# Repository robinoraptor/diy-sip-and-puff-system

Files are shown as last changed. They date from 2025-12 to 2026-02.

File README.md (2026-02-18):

# Sip & Puff Mouse Controller

> Ein adaptives Eingabesystem für Menschen mit eingeschränkter Fingermotorik

Prototyp v3.0 b

---

## 📖 Über das Projekt

Dieses Projekt entstand im Rahmen eines **Human Factors (HF) Projekts** in Kooperation mit der **Hochschule Furtwangen** und **Musiklusion** (https://www.musiklusion.de/mundmaus/) und verfolgt die Fragestellung:

> **"Wie können durch eine Assistenzlösung zusätzliche, intuitiv nutzbare Freiheitsgrade geschaffen werden, die Menschen mit eingeschränkter Fingermotorik das selbstständige Ausführen der Maussteuerung ermöglichen?"**

### Definition Freiheitsgrad

*"Ein Freiheitsgrad ist eine (kontinuierliche) Dimension, die vom Eingabegerät erfasst und vom Benutzer unabhängig gesteuert werden kann."*  
— Seinfeld et al. (2020): User Representations in Human-Computer Interaction

---

## 🎯 Projektziele

Das System wurde entwickelt mit Fokus auf:

1. **Ausdrucksstarke Schnittstelle**  
   Maximaler digitaler Output bei minimalem physischem Aufwand

2. **Nutzerzentrierung**  
   Übertragbarkeit auf alle Menschen mit ähnlichen Einschränkungen

3. **Alltagsverbesserung**  
   Mehr Selbstständigkeit bei der PC-Bedienung für Menschen mit Einschränkungen

4. **Intuitive Bedienung**  
   Natürliche Interaktion durch Sip & Puff (Saug- und Blastechnik)

### Inspiration

Das Projekt orientiert sich an professionellen Assistenzsystemen wie dem **Quadstick** und ähnlichen kommerziellen Produkten, bietet aber eine **Open-Source-Alternative** zum Selbstbau.

---

## 🔄 Entwicklungsprozess & Prototypen

Die Entwicklung erfolgte iterativ in mehreren Prototyp-Versionen:

### Version 1.0 - Proof of Concept
Prototyp v1.0 a
Prototyp v1.0 b

**Features:**
- Basis-Funktionalität (Sip & Puff für Klicks)
- Joystick für 2D-Mausbewegung
- Lötverbindung der Komponenten
- Einfacher Arduino-Code

**Erkenntnisse:**
- Drucksensor-Kalibrierung essentiell
- Schwellwerte müssen anpassbar sein
- Deadzone notwendig für präzise Steuerung
- Geschwindigkeitsanpassung wichtig

### Version 2.0 - GUI-gesteuert
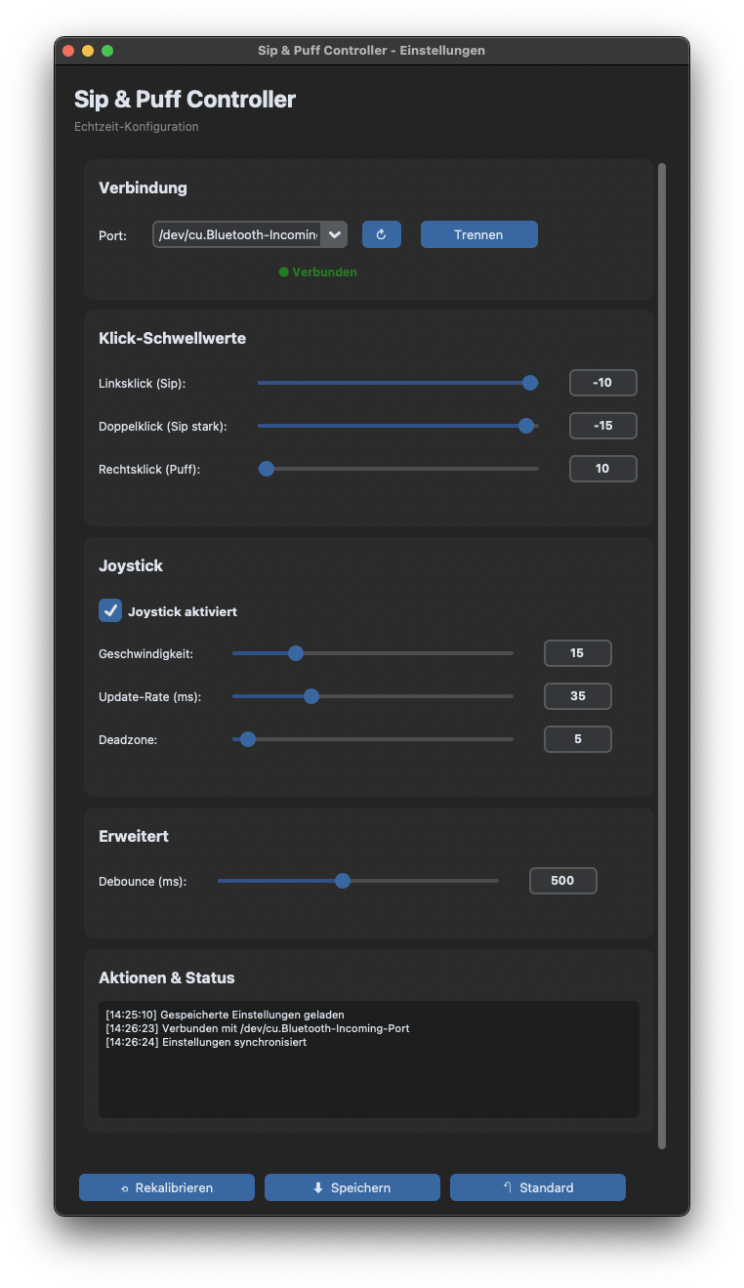
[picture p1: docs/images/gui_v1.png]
GUI v1.0

Prototyp v2.0 a
Prototyp v2.0 b

**Features:**
- Erste vollständige GUI-Integration
- Echtzeit-Parameteranpassung
- Persistente Einstellungen
- Moderne CustomTkinter-UI
- Breiteres Mundstück
- Erweiterung des Mundstücks um Luer-Lock-Adapter um optinalen PTFE-Atemfilter hinzuzufügen

**Erkenntnisse:**
- Live-Anpassung drastisch verbessert Nutzbarkeit
- Individuelle Profile essentiell
- Begrenzung der Bakterienbildung essentiell

### Version 3.0 - Polished Prototype
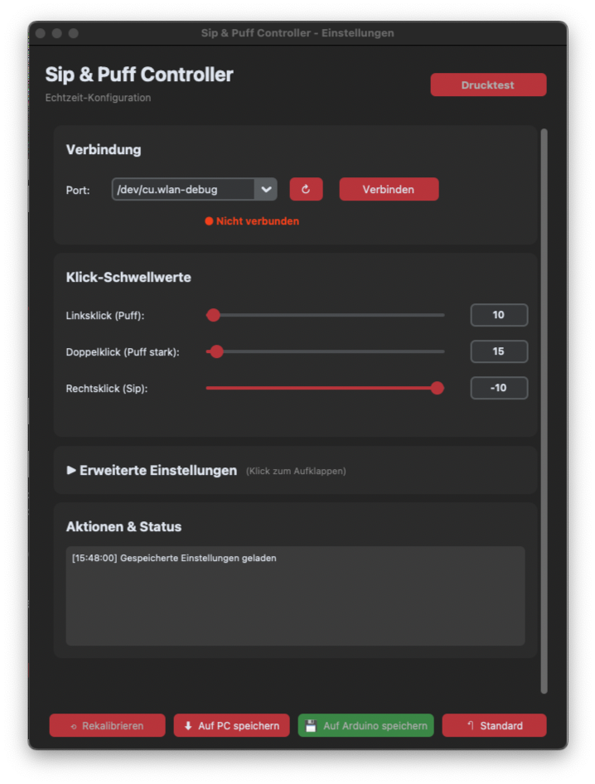
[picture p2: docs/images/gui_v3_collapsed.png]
GUI v2.0

Prototyp v3.0 a
Prototyp v3.0 b

**Features:**
- Überarbeitete GUI für übersichtlichere Bedienung
- Exportieren der GUI als eigenständige Desktop-Anwendung möglich
- Speichern der Einstellungen auf dem Gerät selbst (Plug & Play)
- Überarbeitung der Scroll-Funktionalität durch Mappen auf Joyatick-Bewegungen
- Schlichtes und modernes Gehäuse für die Technik
- Einfaches Austuschen der Gelenkarmverbindung

**Erkenntnisse:**
- Speichern auf Gerät erhöht Plug & Play Charakter drastisch
- Überdecken von verbauten LEDs verhindern mögliche Ablenkungen
- Austauschbarkeit der Armverbingung trägt zur erhöhter Unabhängigkeit bei

---

## ✨ Features

### Hardware
- ✅ **MPXV7002DP Drucksensor** für bidirektionale Druckmessung (Saugen/Blasen)
- ✅ **Analoger Joystick** für präzise 2D-Mausbewegung oder Scrollen
- ✅ **Arduino Pro Micro** als USB-HID-Gerät (native Mausfunktion)
- ✅ **Modularer Aufbau** für einfache Anpassungen

### Software
- ✅ **Moderne GUI** mit CustomTkinter für Echtzeit-Konfiguration
- ✅ **Live-Parameteranpassung** ohne Arduino-Neustart
- ✅ **Persistente Einstellungen** (JSON & Arduino EEPROM)
- ✅ **Drei Klick-Modi**: Linksklick, Doppelklick, Rechtsklick
- ✅ **Scroll-Funktionalität** für vertikales Scrollen
- ✅ **Adaptive Schwellwerte** (-400 bis +400)
- ✅ **Joystick aktivierbar/deaktivierbar**
- ✅ **Standalone Desktop-Anwendung** (.app/.exe) ohne Python-Installation

GUI Screenshot

---

## 🛠️ Hardware-Komponenten

| Komponente | Typ | Funktion | Ungefähre Kosten | Link |
|---|-----|---|---|---|
| Arduino Pro Micro | ATmega32U4 | Mikrocontroller mit nativer USB-HID-Unterstützung | ~8 € | https://www.amazon.de/EntwicklungBoards-Binghe-Mikrocontroller-Entwicklungsboard-Selbst-USB-Updater/dp/B0D69JLJ97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 |
| MPXV7002DP | Drucksensor | Bidirektionaler Differenzdrucksensor (±2 kPa) | ~24 € | https://www.amazon.de/dp/B08D6JDJ4D?ref=ppx_yo2ov_dt_b_fed_asin_title |
| Analoger Joystick | 2-Achsen | XY-Achsen für Mausbewegung | ~1 € | https://www.roboter-bausatz.de/p/joystick-modul-2-achsen |
| Schlauch 2.5mm ID x 4mm OD x 1m | Silikon (Lebensmittelecht) | Für Sip & Puff Eingabe | ~4 € | https://www.amazon.de/dp/B0BZXR88VD?ref=ppx_yo2ov_dt_b_fed_asin_title&th=1 |
| Schlauch 3mm ID x 6mm OD x 1.5m | Silikon (Lebensmittelecht) | Für Sip & Puff Eingabe | ~5 € | https://www.amazon.de/dp/B0CXPW74GZ?ref=ppx_yo2ov_dt_b_fed_asin_title&th=1 |
| PTFE Filter | Hydrophob | Hygiene & Schutz gegen Flüssigkeit | ~14 € | https://www.amazon.de/dp/B07KWW7ZXF?ref=ppx_yo2ov_dt_b_fed_asin_title&th=1 |
| Luer Lock Adapter | Weiblich | Verbindung von Filter & Schlauch | ~7 € | https://www.amazon.de/dp/B0BMFJSJP1?ref=ppx_yo2ov_dt_b_fed_asin_title |
| Luer Lock Adapter | Männlich | Verbindung von Filter & Schlauch | ~8 € | https://www.amazon.de/dp/B0B8CJVX3S?ref=ppx_yo2ov_dt_b_fed_asin_title |
| Diverse | Kabel, LEDs, Gehäuse | Verkabelung und Montage | ~5-10 € |
| **Gesamt** | | | **~75-80 €** |

---

## 🔌 Schaltplan

### Pin-Belegung Arduino Pro Micro

```
MPXV7002DP Drucksensor:
├─ VCC  → 5V (Arduino)
├─ GND  → GND (Arduino)
└─ OUT  → A0 (Analog)

Joystick:
├─ VCC  → RAW (5V Arduino)
├─ GND  → GND (Arduino, optional über Kippschalter)
├─ VRx  → A2 (Analog)
└─ VRy  → A1 (Analog)

Optionaler Reset-Button (Für Debugging):
├─ Pin 1 → GND
└─ Pin 2 → RST
```

---

## 📦 Installation

### Voraussetzungen

**Hardware:**
- Arduino Pro Micro (oder kompatibel)
- USB-Kabel (Micro-USB)
- Aufgebaute Schaltung (siehe Schaltplan)

**Software:**
- [PlatformIO](https://platformio.org/) oder Arduino IDE
- Python 3.7+ (für GUI-Entwicklung, nicht für fertige Desktop-App)
- Git (optional)

### 1. Repository klonen

```bash
git clone https://github.com/robinoraptor/sip-puff-controller.git
cd sip-puff-controller
```

### 2. Arduino-Code flashen

#### Mit PlatformIO (empfohlen):

```bash
cd arduino/
pio run --target upload
```

#### Mit Arduino IDE:
1. `arduino/src/main.cpp` öffnen
2. Board auswählen: **Tools → Board → SparkFun Pro Micro (5V, 16 MHz)**
3. Port auswählen: **Tools → Port → [Dein Port]**
4. Hochladen: **Sketch → Upload**

### 3. GUI verwenden

#### Python-Version (für Entwickler)

**Automatisch:**

**Linux/macOS:**
```bash
cd gui/
./start_gui.sh
```

**Windows:**
```bash
cd gui/
start_gui.bat
```

**Manuell:**

```bash
cd gui/
pip install -r requirements.txt
python sippuff_gui.py
```

---

## 🖥️ Desktop-Anwendung erstellen

Du möchtest die GUI als **standalone .app/.exe** verteilen, ohne dass Python installiert sein muss?

### Voraussetzungen

```bash
cd gui/
pip install -r requirements.txt
```

Das installiert automatisch auch PyInstaller.

### Build-Prozess

#### macOS (.app):

```bash
cd gui/

# Build-Script ausführbar machen (nur einmal nötig)
chmod +x build_mac_linux.sh

# Desktop-App erstellen
./build_mac_linux.sh
```

**Ergebnis:** `dist/SipPuffController.app` (~90-130 MB)

#### Windows (.exe):

```cmd
cd gui

:: Desktop-App erstellen
build_windows.bat
```

**Ergebnis:** `dist\SipPuffController.exe` (~80-120 MB)

#### Linux (Binary):

```bash
cd gui/

# Build-Script ausführbar machen (nur einmal nötig)
chmod +x build_mac_linux.sh

# Desktop-App erstellen
./build_mac_linux.sh
```

**Ergebnis:** `dist/SipPuffController` (~90-130 MB)

### Die fertige Anwendung

Nach dem Build findest du die Anwendung in `gui/dist/`:

```
gui/
├── dist/
│   └── SipPuffController.app    (Mac)
│       SipPuffController.exe    (Windows)
│       SipPuffController        (Linux)
└── build/                        (temporäre Dateien)
```

**Die Anwendung enthält:**
- ✅ Python Runtime
- ✅ Alle Bibliotheken (CustomTkinter, PySerial, etc.)
- ✅ GUI-Code
- ✅ Theme-Dateien
- ✅ Komplettes System in einer Datei!

### Verteilen

**Einfach die .app/.exe kopieren und weitergeben!**

Keine Installation nötig, einfach:
1. Kopieren auf anderen Computer
2. Doppelklick
3. Arduino anschließen
4. Fertig! 🚀

### Wichtige Hinweise

**macOS:**
- Beim ersten Start: Rechtsklick → "Öffnen" (wegen Gatekeeper)
- Oder: Systemeinstellungen → Sicherheit → "Trotzdem öffnen"

**Windows:**
- Antivirus könnte Warnung zeigen (False Positive)
- "Weitere Informationen" → "Trotzdem ausführen"

**Linux:**
- Ausführbar machen: `chmod +x SipPuffController`
- Dann starten: `./SipPuffController`

### Build bereinigen

```bash
# Alte Builds löschen
cd gui/
rm -rf dist/ build/ *.spec

# Neu builden
./build_mac_linux.sh  # oder build_windows.bat
```

---

## 🚀 Verwendung

### Ersteinrichtung

1. **Arduino anschließen**
   - System kalibriert automatisch beim Start
   - ⚠️ **Wichtig:** NICHT in den Schlauch pusten/saugen während der Kalibrierung!

2. **GUI starten**
   - Desktop-App: Doppelklick auf `.app`/`.exe`
   - Oder: `python sippuff_gui.py`

3. **Verbinden**
   - Port auswählen (z.B. COM3 oder /dev/ttyACM0)
   - "Verbinden" klicken
   - GUI lädt automatisch die Arduino-Einstellungen

4. **Einstellungen anpassen**
   - Mit Slidern experimentieren
   - Echtzeit-Feedback im Log
   - Drucktest nutzen für optimale Schwellwerte

#### Standard-Belegung:

| Aktion | Eingabe | Beschreibung |
|---|---|---|
| **Linksklick** | Puff (Blasen) > 10 | Leichtes Blasen |
| **Doppelklick** | Puff (Blasen) > 15 | Kräftiges Blasen |
| **Rechtsklick** | Sip (Saugen) < -10 | Leichtes Ansaugen |
| **Scroll Up** | Joystick | horizontale Bewegung nach Links |
| **Scroll Down** | Joystick | horizontale Bewegung nach Rechts |
| **Mausbewegung** | Joystick | 2D-Bewegung in alle Richtungen |

#### Anpassbare Parameter:

**Klick-Schwellwerte:**
- Linksklick (Puff): 0 bis 400
- Doppelklick (Puff): 0 bis 400
- Rechtsklick (Sip): -400 bis 0

**Joystick:**
- Geschwindigkeit: 5-50
- Update-Rate: 10-100ms
- Deadzone: 0-100

**Weitere:**
- Debounce: 100-1000ms
- Joystick an/aus
- Scroll an/aus

### Einstellungen speichern

**Auf PC speichern:**
- Klicke "⬇ Auf PC speichern"
- Wird in `~/.sippuff/sippuff_config.json` gespeichert
- Funktioniert auch in Desktop-App!

**Auf Arduino speichern:**
- Klicke "💾 Auf Arduino speichern"
- Wird im Arduino EEPROM gespeichert
- Arduino funktioniert jetzt **Plug & Play** - auch ohne PC!
- Einstellungen bleiben dauerhaft erhalten

**Standard wiederherstellen:**
- Klicke "↶ Standard"
- Lädt Standardwerte aus `sippuff_defaults.json`

### Workflow: Arduino als Master

Das System ist so konzipiert, dass **der Arduino die Einstellungen speichert**:

```
1. Arduino anschließen
2. GUI öffnen → Verbinden
3. GUI lädt automatisch Arduino-Einstellungen ✅
4. In GUI anpassen (optional)
5. "💾 Auf Arduino speichern" (optional)
6. Beim nächsten Start: Arduino hat alles gespeichert!
```

**Vorteil:** Arduino funktioniert überall gleich - egal an welchem PC!

---

## 🔧 Konfiguration

### Schwellwerte anpassen

Die Empfindlichkeit kann individuell angepasst werden:

```
Für Nutzer mit schwächerer Atemkontrolle:
├─ Linksklick (Puff): 5
├─ Doppelklick (Puff): 8
├─ Rechtsklick (Sip): -5
├─ Scroll Down (Puff): 3
└─ Scroll Up (Sip): -3

Für Nutzer mit stärkerer Atemkontrolle:
├─ Linksklick (Puff): 30
├─ Doppelklick (Puff): 50
├─ Rechtsklick (Sip): -30
├─ Scroll Down (Puff): 10
└─ Scroll Up (Sip): -10
```

**Tipp:** Nutze den **Drucktest** in der GUI, um deine optimalen Werte zu finden!

### Standard-Werte ändern

Editiere `~/.sippuff/sippuff_defaults.json`:

```json
{
  "click_left": 10,
  "click_double": 15,
  "click_right": -10,
  "scroll_up": -5,
  "scroll_down": 5,
  "scroll_speed": 1,
  "scroll_enabled": true,
  "wavelength": 15,
  "period": 35,
  "deadzone": 25,
  "debounce": 500,
  "joystick_enabled": true
}
```

---

## 🔬 Technische Details

### Arduino-Firmware

- **Sprache:** C++ (Arduino Framework)
- **Bibliotheken:** `Mouse.h` (native USB-HID), `EEPROM.h`
- **Sampling-Rate:** 100 Hz (10ms Loop)
- **Kalibrierung:** Automatisch beim Start (50 Samples, 1 Sekunde)
- **Serial-Protokoll:** 115200 Baud für GUI-Kommunikation
- **Persistenz:** EEPROM-Speicher für Plug & Play Betrieb

### GUI-Anwendung

- **Framework:** CustomTkinter (moderne UI)
- **Kommunikation:** PySerial
- **Architektur:** Event-driven mit Threading
- **Build-System:** PyInstaller für standalone Apps
- **Config-Speicher:** `~/.sippuff/` (User-Home-Directory)
- **Plattformen:** Windows, macOS, Linux

### Desktop-App Details

**PyInstaller-Build:**
- `--onefile`: Einzelne ausführbare Datei
- `--windowed`: Keine Konsole (nur GUI)
- `--add-data`: Theme-Dateien eingebettet
- Alle Abhängigkeiten inkludiert
- Keine Python-Installation erforderlich

**Dateigröße:**
- Mac: ~90-130 MB (.app Bundle)
- Windows: ~80-120 MB (.exe)
- Linux: ~90-130 MB (Binary)

---

## 📚 Wissenschaftlicher Hintergrund

### Literatur

**Seinfeld, S., Feuchtner, T., Maselli, A. & Müller, J. (2020).**  
*User Representations in Human-Computer Interaction.*  
Human-Computer Interaction, 36(5–6), 400–438.  
https://doi.org/10.1080/07370024.2020.1724790

### Verwandte Projekte

- **Quadstick** - Kommerzielles Sip & Puff System
- **Xbox Adaptive Controller** - Microsoft's Adaptive Gaming Controller

---

## ⚠️ Sicherheitshinweise

### Wichtig für die Nutzung:

1. **Hygiene**
   - Mundstück täglich reinigen/desinfizieren
   - Schlauch regelmäßig austauschen
   - Bei mehreren Nutzern: individuelle Mundstücke verwenden

2. **Gesundheit**
   - Bei Schwindel/Unwohlsein sofort pausieren
   - Nicht zu stark/häufig pusten (Hyperventilation vermeiden)
   - Regelmäßige Pausen einlegen

3. **Technisch**
   - System nicht unbeaufsichtigt mit anderen Nutzern betreiben
   - Bei Fehlfunktion sofort vom Computer trennen
   - Keine Modifikationen an medizinischen Komponenten

4. **Medizinisch**
   - Dieses System ist **kein medizinisches Produkt**
   - Keine CE-Kennzeichnung für Medizinprodukte
   - Bei medizinischer Nutzung: Rücksprache mit Fachpersonal

---

## 🎓 Hochschule Furtwangen

Entwickelt im Rahmen eines Human Factors Projekts an der **Hochschule Furtwangen University (HFU)**.

**Fakultät:** Engineering Technology  
**Studiengang:** Human Factors  
**Semester:** 2. Semester

---

## 📄 Lizenz

Dieses Projekt steht unter der MIT-Lizenz - siehe [LICENSE](LICENSE) für Details.

---

## 🤝 Beitragen

Contributions sind willkommen! Bitte öffne ein Issue oder Pull Request auf GitHub.

---

## 📧 Kontakt

Bei Fragen oder Anregungen:
- GitHub Issues: [github.com/robinoraptor/sip-puff-controller/issues](https://github.com/robinoraptor/sip-puff-controller/issues)

---

**Entwickelt mit ❤️ für Assistive Technology**

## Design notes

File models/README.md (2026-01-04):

# Bauteile

---

In diesen Ordnern sind alle Dateien zu den physischen Bauteilen zu finden, die mittels 3D-Druck-Verfahren hergestellt werden müssen. In manche Teile sind Einschmelzgewinde einzulassen. Diese werden mit einem Lötkolben oder Ähnlichem erhitzt und in das fertige Bauteil gedrückt. Somit sorgen diese für eine stärkere und nachhaltigere Verbindung. Sollten keine Einschmelzgewinde vorhanden sein, können die STEP-Dateien so bearbeitet werden, dass eine Schraube alleine für die Fixierung ausreichend ist. Für den Mainframe, an den die elektronischen Bauteile befestigt werden, werden 11 M2 Gewinde mit den Maßen 3x3.5mm verwendet. Zur Befestigung werden 6 M2x4mm Schrauben verwendet. Das Frontcover wird am Mainframe mit Hilfe von 2 M2x6mm Schrauben befestigt. Das Backcover wiederum benötigt 3 M2x4mm Schrauben. Dort werden zudem 4 3x3.5mm Einschmelzgewinde eingesetzt, um einen Adapter zu einem Gelenkarm zu befestigen. Mit dem Bereitgestellten BallJointAdapter benötigt man 4 M2x6mm und diesen an dem Gerät zu befestigen.

---

## STEP-Dateien

Die STEP-Dateien können in CAD-Programmen wie Shapr3D weiter angepasst werden. Hier können zum Beispiel Maße auf andere Bauteile oder Befestigungsmöglichkeiten angepasst werden.

## 3MF-Dateien

Die 3MF-Dateien können direkt in das 3D-Druck Slicer Programm BambuStudio gezogen werden. Dieser Slicer wird empfohlen, wenn die 3D-Drucker von BambuLab verwendet werden. Diese Dateien beinhalten alle Druck-Einstellungen, die für den ersten Bau verwendet wurden.

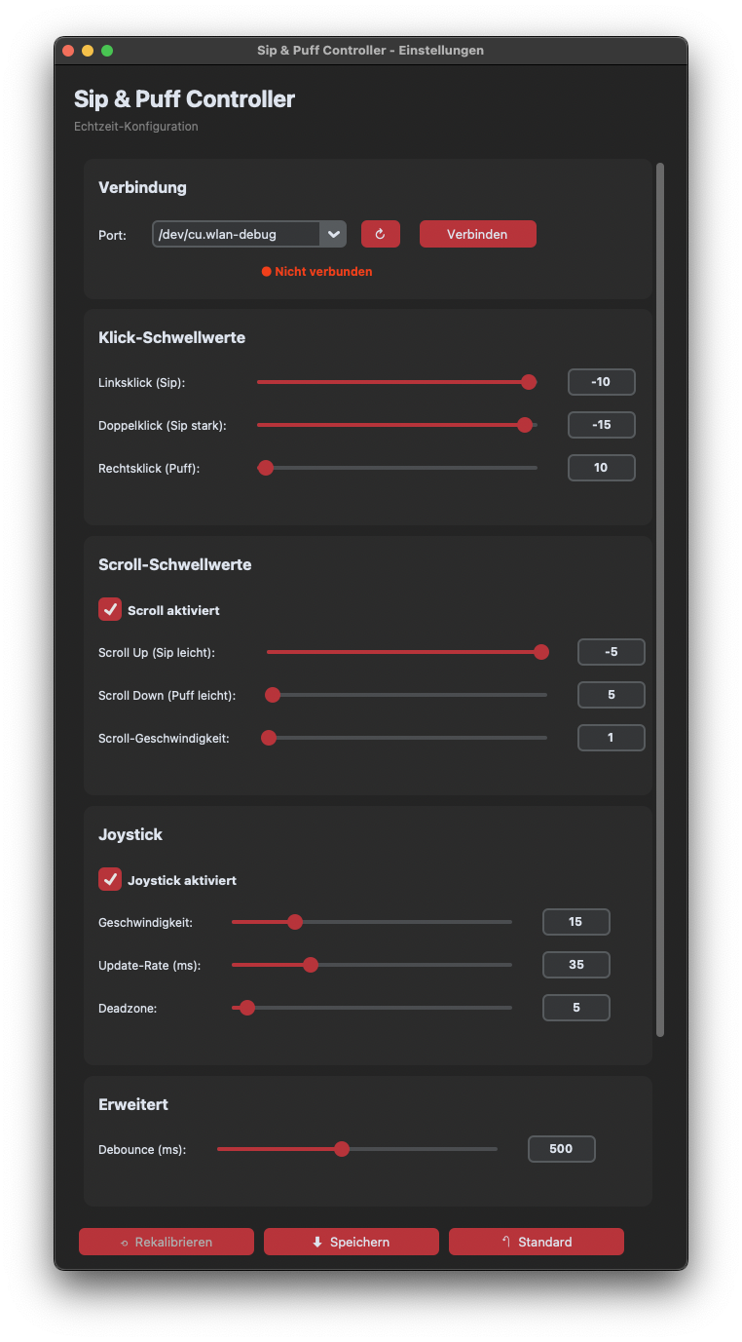
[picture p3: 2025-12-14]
docs/images/gui_v2.png

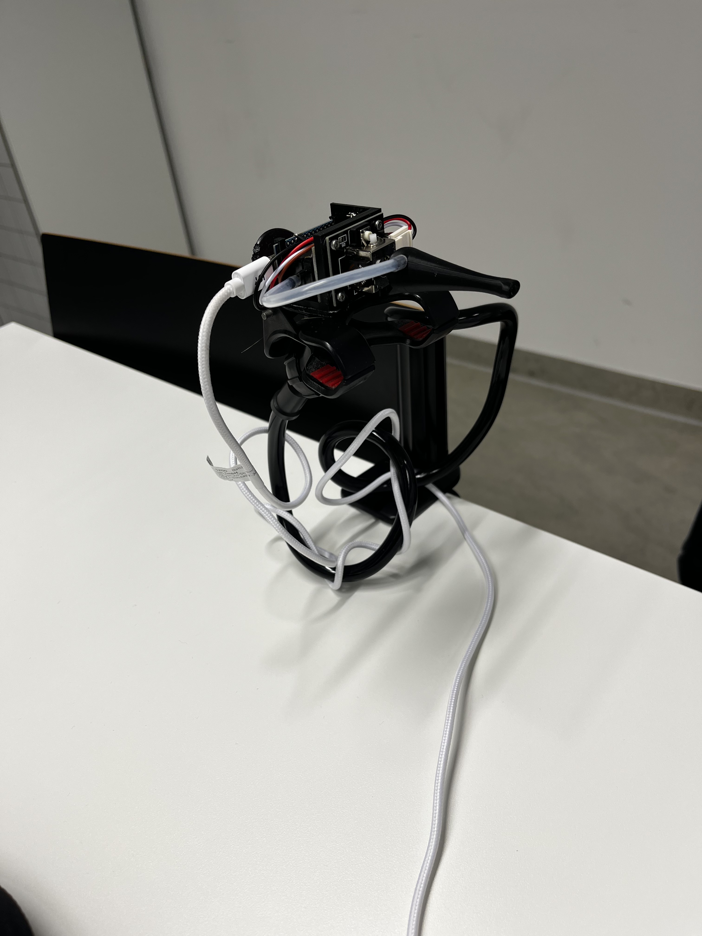
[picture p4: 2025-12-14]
docs/images/prototype_v1_b.jpg

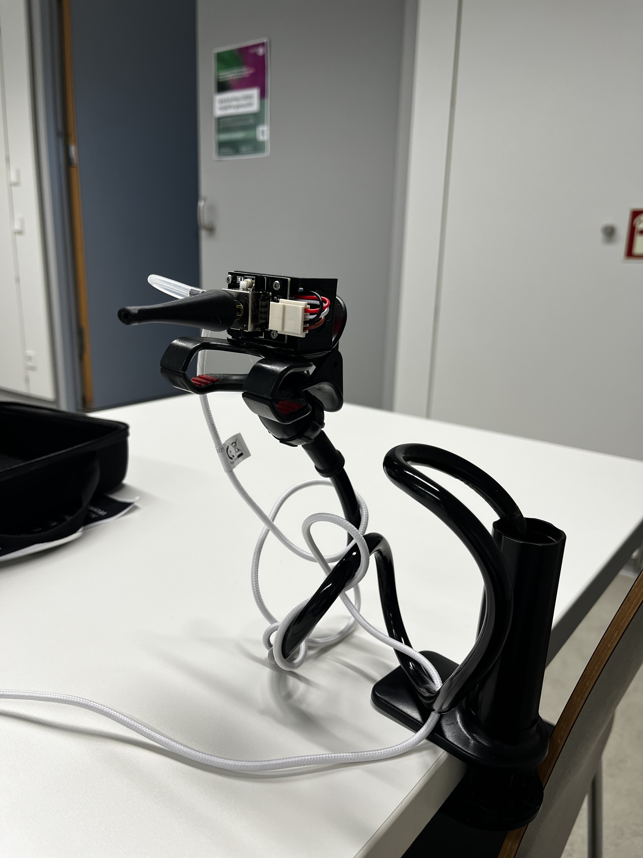
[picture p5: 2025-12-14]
docs/images/prototype_v1_a.jpg

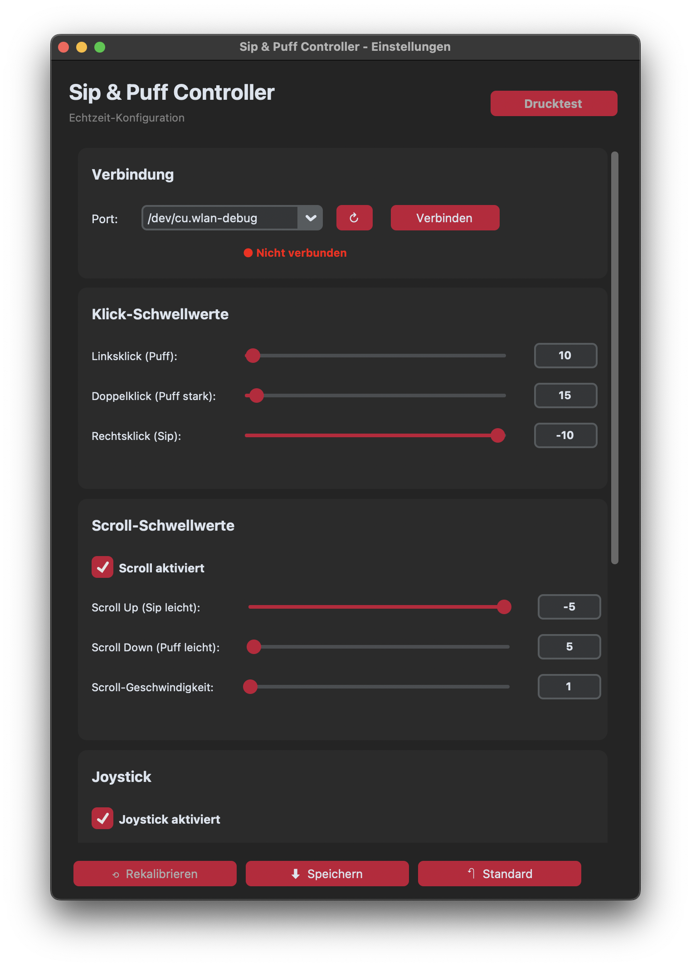
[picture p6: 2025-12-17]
docs/images/gui_v3.png

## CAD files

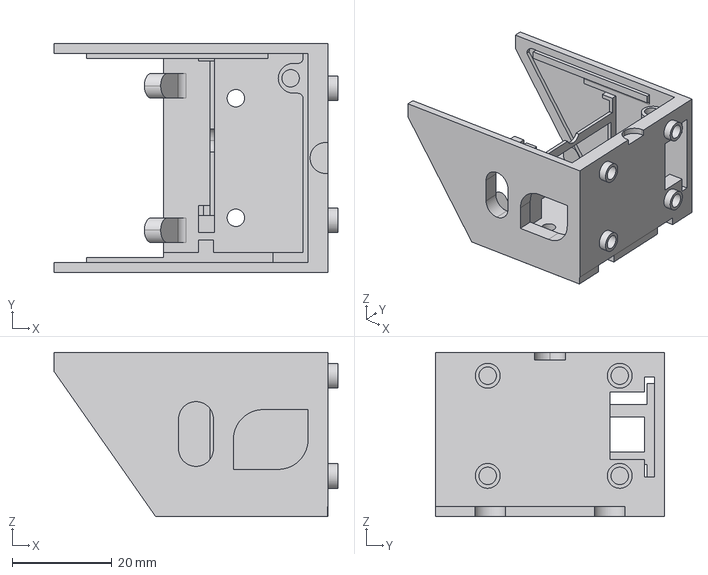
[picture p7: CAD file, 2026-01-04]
models/Step/Mainframe.step
57.0 x 46.0 x 33.0 mm

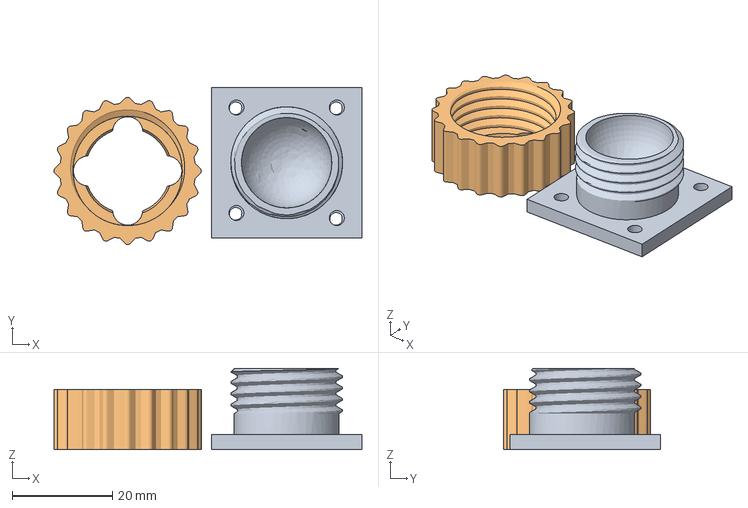
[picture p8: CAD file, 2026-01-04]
models/3mf/BallJointAdapter.3mf
61.3 x 31.3 x 16.2 mm
Ball Socket Lock1.stl_3
nut.stl

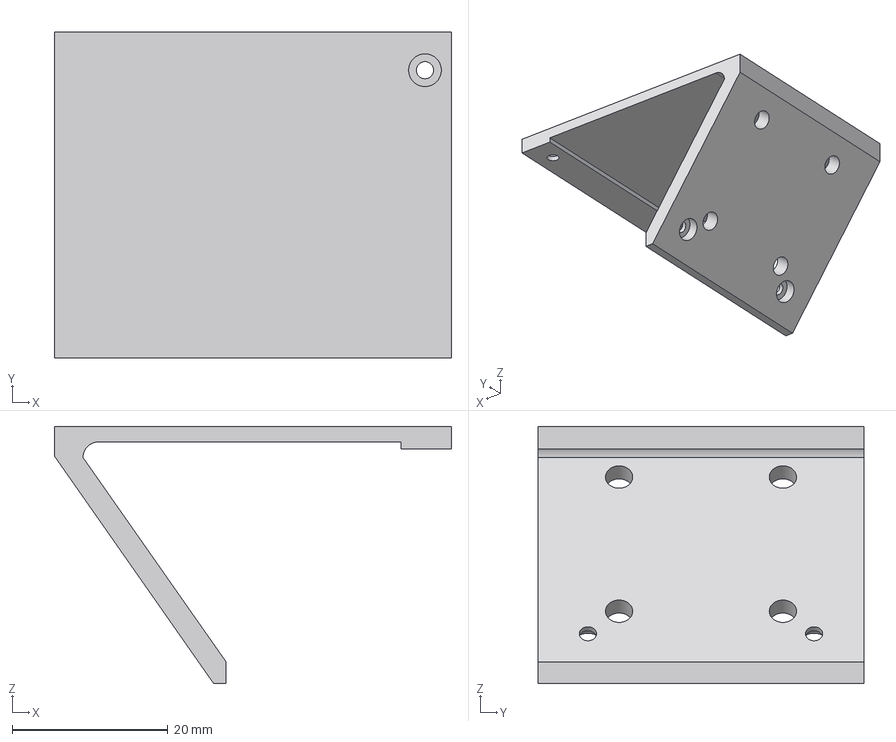
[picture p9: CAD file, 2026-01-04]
models/Step/Backcover.step
50.9 x 41.8 x 33.0 mm

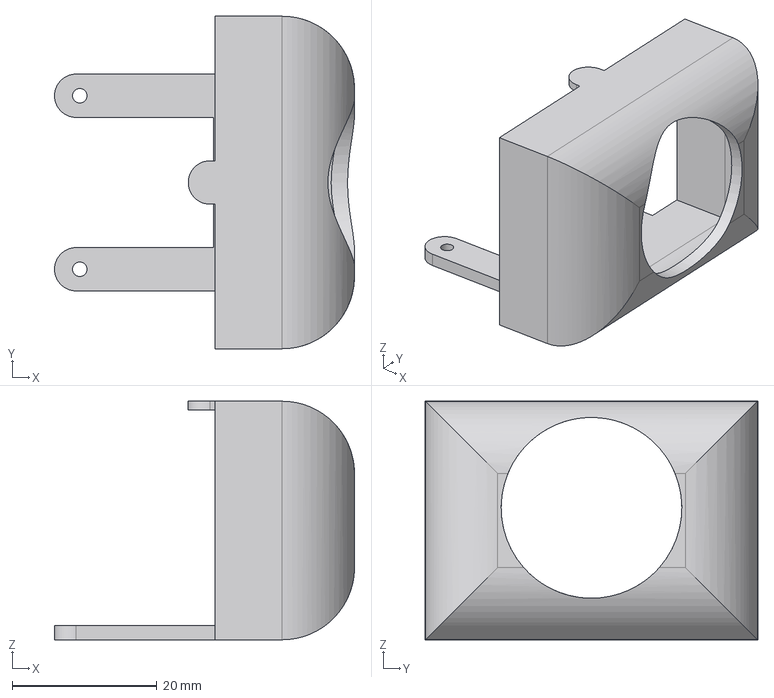
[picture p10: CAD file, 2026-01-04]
models/Step/Frontcover.step
41.5 x 46.0 x 33.0 mm

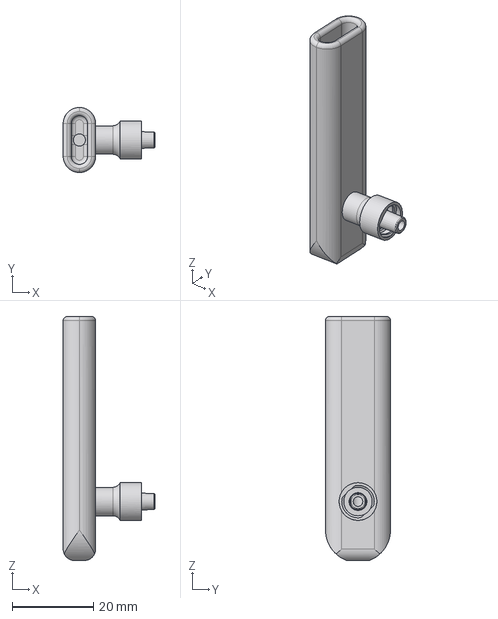
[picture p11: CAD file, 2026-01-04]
models/Step/Mouthpiece.step
22.6 x 16.0 x 60.0 mm

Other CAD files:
models/3mf/Backcover.3mf
models/3mf/Frontcover.3mf
models/3mf/Mainframe.3mf
models/3mf/Mouthpiece.3mf
models/Stl/Backcover.stl
models/Stl/Frontcover.stl
models/Stl/Mainframe.stl
models/Stl/Mouthpiece.stl

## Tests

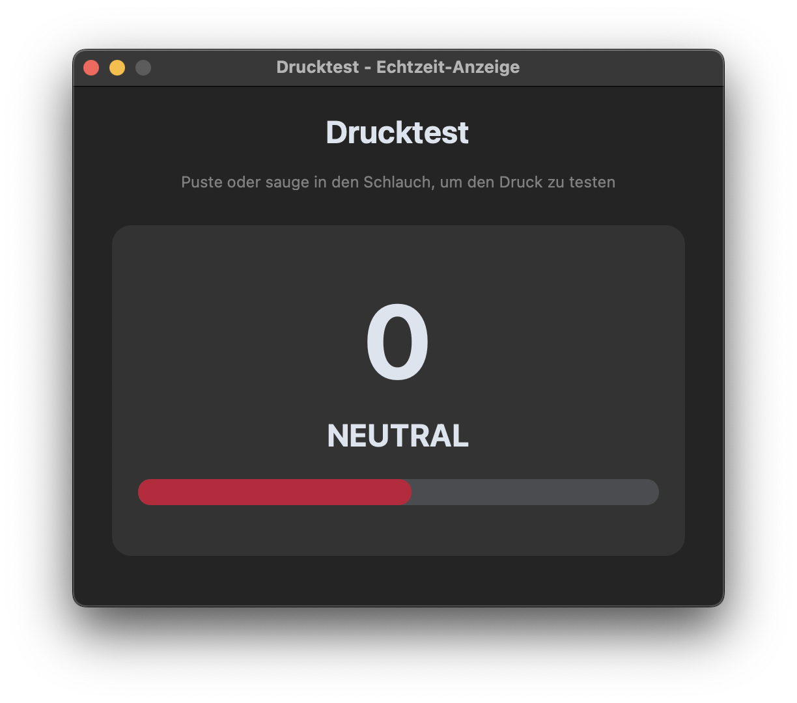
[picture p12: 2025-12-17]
docs/images/gui_pressure_test.png

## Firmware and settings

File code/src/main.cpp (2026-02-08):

// Sip and Puff Mouse Controller with GUI Configuration

#include <Mouse.h>
#include <EEPROM.h>

// Pin-Definitionen
const int PRESSURE_PIN = A0; // MPXV7002DP Drucksensor
const int JOY_X_PIN = A2;    // Joystick X-Achse
const int JOY_Y_PIN = A1;    // Joystick Y-Achse

// Kalibrierung
int pressureBaseline = 0; // Nullpunkt bei Umgebungsdruck
const int SAMPLES = 50;   // Anzahl Samples für Kalibrierung

// Klick-Schwellwerte (über Serial änderbar)
int clickLeft = 10;   // Einfacher Linksklick (Pusten)
int clickDouble = 15; // Doppelter Linksklick (starkes Pusten)
int clickRight = -10; // Rechtsklick (Saugen)

// Scroll-Schwellwerte (über Serial änderbar)
int scrollUp = -5;         // Scroll nach oben (leichtes Saugen)
int scrollDown = 5;        // Scroll nach unten (leichtes Pusten)
int scrollSpeed = 1;       // Scroll-Geschwindigkeit (1-5)
bool scrollEnabled = true; // Scroll aktivierbar/deaktivierbar

// Debouncing für Klicks
unsigned long lastClickTime = 0;
unsigned long clickDebounce = 500; // 500ms zwischen Klicks

// Joystick-Einstellungen (über Serial änderbar)
const int JOY_CENTER = 512; // Mittelposition des Joysticks
int joyDeadzone = 10;       // Deadzone um Mittelposition
int wavelength = 15;        // Geschwindigkeit in Pixel pro Iteration
int period = 35;            // Update-Intervall in MS
unsigned long cursorFrequencyTimer = 0;

// Joystick-Aktivierung
bool joystickEnabled = false;

// Status-LED
const int LED_PIN = LED_BUILTIN_TX;

// Serial-Kommando-Buffer
String serialBuffer = "";
bool commandReady = false;

// Drucktest-Modus
bool pressureTestMode = false; // Wenn true, sende kontinuierlich Druckwerte

// EEPROM-Speicherung
const int EEPROM_ADDRESS = 0;
const uint16_t EEPROM_MAGIC = 0xA5B7;

struct Settings
{
  uint16_t magic;
  int clickLeft;
  int clickDouble;
  int clickRight;
  int scrollUp;
  int scrollDown;
  int scrollSpeed;
  bool scrollEnabled;
  int wavelength;
  int period;
  int joyDeadzone;
  unsigned long clickDebounce;
  bool joystickEnabled;
};

// Function Prototypes
void calibratePressureSensor();
void handleClicks(int pressureDiff);
void handleScrolling(int pressureDiff);
void handleMouseMovement();
void blinkLED(int times);
void processSerialCommand(String cmd);
void sendCurrentSettings();
void saveSettingsToEEPROM();
void loadSettingsFromEEPROM();
void resetToDefaults();

void setup()
{
  pinMode(LED_PIN, OUTPUT);
  digitalWrite(LED_PIN, HIGH);

  Serial.begin(115200);
  delay(1000);

  Serial.println(F("================================="));
  Serial.println(F("  Sip & Puff Mouse Controller"));
  Serial.println(F("  mit GUI-Konfiguration"));
  Serial.println(F("  + Scroll-Funktion"));
  Serial.println(F("  + EEPROM-Speicherung"));
  Serial.println(F("================================="));
  Serial.println();

  // Lade gespeicherte Einstellungen aus EEPROM
  loadSettingsFromEEPROM();

  // Kalibrierung des Drucksensors
  calibratePressureSensor();

  // Maus initialisieren
  Mouse.begin();

  // Timer initialisieren
  cursorFrequencyTimer = millis() + period;

  Serial.println(F("\n>>> Controller aktiv <<<"));
  Serial.println(F("Bereit für GUI-Verbindung\n"));

  // Sende aktuelle Einstellungen
  sendCurrentSettings();

  digitalWrite(LED_PIN, LOW);
  delay(500);
}

void loop()
{
  // Serial-Kommandos verarbeiten
  while (Serial.available() > 0)
  {
    char c = Serial.read();
    if (c == '\n')
    {
      commandReady = true;
    }
    else
    {
      serialBuffer += c;
    }
  }

  if (commandReady)
  {
    processSerialCommand(serialBuffer);
    serialBuffer = "";
    commandReady = false;
  }

  // Drucksensor auslesen
  int pressureRaw = analogRead(PRESSURE_PIN);
  int pressureDiff = pressureRaw - pressureBaseline;

  // Drucktest-Modus: Sende kontinuierlich Werte
  if (pressureTestMode)
  {
    // Sende NUR den Wert
    Serial.println(pressureDiff);
    delay(200); // 5Hz Update-Rate für Stabilität
  }
  else
  {
    // Normaler Betrieb: Mausklicks über Sip & Puff
    handleClicks(pressureDiff);

    // Scrolling über leichtes Sip & Puff
    if (scrollEnabled)
    {
      handleScrolling(pressureDiff);
    }

    // Mausbewegung über Joystick
    if (joystickEnabled && millis() >= cursorFrequencyTimer)
    {
      handleMouseMovement();
      cursorFrequencyTimer = millis() + period;
    }

    delay(10);
  }
}

void calibratePressureSensor()
{
  Serial.println(F("Kalibriere Drucksensor..."));
  Serial.println(F("Bitte NICHT in Schlauch pusten/saugen!"));

  long sum = 0;

  for (int i = 0; i < SAMPLES; i++)
  {
    sum += analogRead(PRESSURE_PIN);
    if (i % 10 == 0)
    {
      Serial.print(F("."));
    }
    delay(20);
  }

  pressureBaseline = sum / SAMPLES;

  Serial.println();
  Serial.print(F("Kalibrierung abgeschlossen! Nullpunkt: "));
  Serial.println(pressureBaseline);
}

void handleClicks(int pressureDiff)
{
  unsigned long currentTime = millis();

  if (currentTime - lastClickTime < clickDebounce)
  {
    return;
  }

  // Doppelklick (starkes Pusten)
  if (pressureDiff > clickDouble)
  {
    Serial.println(F("ACTION:DOUBLE_CLICK"));
    Mouse.click(MOUSE_LEFT);
    delay(50);
    Mouse.click(MOUSE_LEFT);
    lastClickTime = currentTime;
    blinkLED(2);
  }

  // Einfacher Linksklick (Pusten)
  else if (pressureDiff > clickLeft)
  {
    Serial.println(F("ACTION:LEFT_CLICK"));
    Mouse.click(MOUSE_LEFT);
    lastClickTime = currentTime;
    blinkLED(1);
  }

  // Rechtsklick (Saugen)
  else if (pressureDiff < clickRight)
  {
    Serial.println(F("ACTION:RIGHT_CLICK"));
    Mouse.click(MOUSE_RIGHT);
    lastClickTime = currentTime;
    blinkLED(1);
  }
}

void handleScrolling(int pressureDiff)
{
  // Um Scroll-Richtung zu ändern Mouse.move(0, 0, -1) und Mouse.move(0, 0, 1) tauschen
  int joyX = analogRead(JOY_X_PIN);
  if (joyX < JOY_CENTER - joyDeadzone)
  {
    delay(80);
    Mouse.move(0, 0, -1);
  }
  else if (joyX > JOY_CENTER + joyDeadzone)
  {
    delay(80);
    Mouse.move(0, 0, 1);
  }
}

void handleMouseMovement()
{
  int joyX = analogRead(JOY_X_PIN);
  int joyY = analogRead(JOY_Y_PIN);

  int deltaX = joyX - JOY_CENTER;
  int deltaY = joyY - JOY_CENTER;

  // Deadzone anwenden
  if (abs(deltaX) < joyDeadzone)
  {
    deltaX = 0;
  }
  else
  {
    if (deltaX < 0)
    {
      deltaX += joyDeadzone;
    }
    else
    {
      deltaX -= joyDeadzone;
    }
  }

  if (abs(deltaY) < joyDeadzone)
  {
    deltaY = 0;
  }
  else
  {
    if (deltaY < 0)
    {
      deltaY += joyDeadzone;
    }
    else
    {
      deltaY -= joyDeadzone;
    }
  }

  // Geschwindigkeitsberechnung
  int moveX = deltaX / (1023 / (wavelength * 2));
  int moveY = deltaY / (1023 / (wavelength * 2));

  moveX = -moveX;
  moveY = -moveY;

  if (moveX != 0 || moveY != 0)
  {
    Mouse.move(moveX, moveY, 0);
  }
}

void blinkLED(int times)
{
  for (int i = 0; i < times; i++)
  {
    digitalWrite(LED_PIN, HIGH);
    delay(50);
    digitalWrite(LED_PIN, LOW);
    delay(50);
  }
}

void processSerialCommand(String cmd)
{
  cmd.trim();

  if (cmd.startsWith("SET:"))
  {
    String param = cmd.substring(4);
    int separatorIndex = param.indexOf(':');

    if (separatorIndex > 0)
    {
      String key = param.substring(0, separatorIndex);
      int value = param.substring(separatorIndex + 1).toInt();

      if (key == "CLICK_LEFT")
      {
        clickLeft = value;
        Serial.println(F("OK:CLICK_LEFT"));
      }
      else if (key == "CLICK_DOUBLE")
      {
        clickDouble = value;
        Serial.println(F("OK:CLICK_DOUBLE"));
      }
      else if (key == "CLICK_RIGHT")
      {
        clickRight = value;
        Serial.println(F("OK:CLICK_RIGHT"));
      }
      else if (key == "SCROLL_UP")
      {
        scrollUp = value;
        Serial.println(F("OK:SCROLL_UP"));
      }
      else if (key == "SCROLL_DOWN")
      {
        scrollDown = value;
        Serial.println(F("OK:SCROLL_DOWN"));
      }
      else if (key == "SCROLL_SPEED")
      {
        scrollSpeed = value;
        Serial.println(F("OK:SCROLL_SPEED"));
      }
      else if (key == "SCROLL")
      {
        scrollEnabled = (value == 1);
        Serial.print(F("OK:SCROLL:"));
        Serial.println(scrollEnabled ? "ON" : "OFF");
      }
      else if (key == "WAVELENGTH")
      {
        wavelength = value;
        Serial.println(F("OK:WAVELENGTH"));
      }
      else if (key == "PERIOD")
      {
        period = value;
        Serial.println(F("OK:PERIOD"));
      }
      else if (key == "DEADZONE")
      {
        joyDeadzone = value;
        Serial.println(F("OK:DEADZONE"));
      }
      else if (key == "DEBOUNCE")
      {
        clickDebounce = value;
        Serial.println(F("OK:DEBOUNCE"));
      }
      else if (key == "JOYSTICK")
      {
        joystickEnabled = (value == 1);
        Serial.print(F("OK:JOYSTICK:"));
        Serial.println(joystickEnabled ? "ON" : "OFF");
      }
    }
  }
  else if (cmd == "GET:SETTINGS")
  {
    sendCurrentSettings();
  }
  else if (cmd == "RECALIBRATE")
  {
    Serial.println(F("INFO:Starte Rekalibrierung..."));
    calibratePressureSensor();
    Serial.println(F("OK:RECALIBRATE"));
  }
  else if (cmd == "PRESSURE_TEST:START")
  {
    pressureTestMode = true;
    Serial.println(F("OK:PRESSURE_TEST:START"));
  }
  else if (cmd == "PRESSURE_TEST:STOP")
  {
    pressureTestMode = false;
    Serial.println(F("OK:PRESSURE_TEST:STOP"));
  }
  else if (cmd == "SAVE_EEPROM")
  {
    saveSettingsToEEPROM();
    Serial.println(F("OK:SAVE_EEPROM"));
  }
  else if (cmd == "LOAD_EEPROM")
  {
    loadSettingsFromEEPROM();
    Serial.println(F("OK:LOAD_EEPROM"));
  }
  else if (cmd == "RESET_DEFAULTS")
  {
    resetToDefaults();
    Serial.println(F("OK:RESET_DEFAULTS"));
  }
}

void sendCurrentSettings()
{
  Serial.println(F("SETTINGS:START"));
  Serial.print(F("CLICK_LEFT:"));
  Serial.println(clickLeft);
  Serial.print(F("CLICK_DOUBLE:"));
  Serial.println(clickDouble);
  Serial.print(F("CLICK_RIGHT:"));
  Serial.println(clickRight);
  Serial.print(F("SCROLL_UP:"));
  Serial.println(scrollUp);
  Serial.print(F("SCROLL_DOWN:"));
  Serial.println(scrollDown);
  Serial.print(F("SCROLL_SPEED:"));
  Serial.println(scrollSpeed);
  Serial.print(F("SCROLL:"));
  Serial.println(scrollEnabled ? "1" : "0");
  Serial.print(F("WAVELENGTH:"));
  Serial.println(wavelength);
  Serial.print(F("PERIOD:"));
  Serial.println(period);
  Serial.print(F("DEADZONE:"));
  Serial.println(joyDeadzone);
  Serial.print(F("DEBOUNCE:"));
  Serial.println(clickDebounce);
  Serial.print(F("JOYSTICK:"));
  Serial.println(joystickEnabled ? "1" : "0");
  Serial.print(F("BASELINE:"));
  Serial.println(pressureBaseline);
  Serial.println(F("SETTINGS:END"));
}

// EEPROM-Funktionen
void saveSettingsToEEPROM()
{
  Serial.println(F("INFO:Speichere Einstellungen in EEPROM..."));

  Settings settings;
  settings.magic = EEPROM_MAGIC;
  settings.clickLeft = clickLeft;
  settings.clickDouble = clickDouble;
  settings.clickRight = clickRight;
  settings.scrollUp = scrollUp;
  settings.scrollDown = scrollDown;
  settings.scrollSpeed = scrollSpeed;
  settings.scrollEnabled = scrollEnabled;
  settings.wavelength = wavelength;
  settings.period = period;
  settings.joyDeadzone = joyDeadzone;
  settings.clickDebounce = clickDebounce;
  settings.joystickEnabled = joystickEnabled;

  EEPROM.put(EEPROM_ADDRESS, settings);

  Serial.println(F("INFO:Einstellungen gespeichert!"));
  blinkLED(3);
}

void loadSettingsFromEEPROM()
{
  Serial.println(F("INFO:Lade Einstellungen aus EEPROM..."));

  Settings settings;
  EEPROM.get(EEPROM_ADDRESS, settings);

  // Prüfe Magic Number
  if (settings.magic == EEPROM_MAGIC)
  {
    // Gültige Einstellungen gefunden
    clickLeft = settings.clickLeft;
    clickDouble = settings.clickDouble;
    clickRight = settings.clickRight;
    scrollUp = settings.scrollUp;
    scrollDown = settings.scrollDown;
    scrollSpeed = settings.scrollSpeed;
    scrollEnabled = settings.scrollEnabled;
    wavelength = settings.wavelength;
    period = settings.period;
    joyDeadzone = settings.joyDeadzone;
    clickDebounce = settings.clickDebounce;
    joystickEnabled = settings.joystickEnabled;

    Serial.println(F("INFO:Gespeicherte Einstellungen geladen!"));
    blinkLED(2);
  }
  else
  {
    // Keine gültigen Einstellungen, behalte Defaults
    Serial.println(F("INFO:Keine gespeicherten Einstellungen gefunden."));
    Serial.println(F("INFO:Verwende Standard-Werte."));
    blinkLED(1);
  }
}

void resetToDefaults()
{
  Serial.println(F("INFO:Setze auf Standard-Werte zurück..."));

  // Standard-Werte
  clickLeft = 10;
  clickDouble = 15;
  clickRight = -10;
  scrollUp = -5;
  scrollDown = 5;
  scrollSpeed = 1;
  scrollEnabled = true;
  wavelength = 15;
  period = 35;
  joyDeadzone = 25;
  clickDebounce = 500;
  joystickEnabled = true;

  saveSettingsToEEPROM();

  Serial.println(F("INFO:Standard-Werte wiederhergestellt!"));
}

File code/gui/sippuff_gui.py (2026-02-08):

#!/usr/bin/env python3
# Sip & Puff Mouse Controller - GUI Configuration Tool

import customtkinter as ctk
from tkinter import messagebox
import serial
import serial.tools.list_ports
import threading
import json
import os
import sys
import time
from datetime import datetime

# PyInstaller-kompatible Pfad-Funktion
def resource_path(relative_path):
    """Get absolute path to resource, works for dev and for PyInstaller"""
    try:
        base_path = sys._MEIPASS
    except Exception:
        base_path = os.path.dirname(os.path.abspath(__file__))
    return os.path.join(base_path, relative_path)

# CustomTkinter Appearance
ctk.set_appearance_mode("system")  # "light" oder "dark"
ctk.set_default_color_theme(resource_path("theme_red.json"))  # Custom Red Theme

class SipPuffGUI:
    def __init__(self, root):
        self.root = root
        self.root.title("Sip & Puff Controller - Einstellungen")
        self.root.geometry("660x850")
        self.root.resizable(True, True)
        
        # Serial-Verbindung
        self.serial_connection = None
        self.connected = False
        
        # Config-Dateien im User-Home-Verzeichnis (funktioniert auch in .app/.exe)
        home_dir = os.path.expanduser("~")
        config_dir = os.path.join(home_dir, ".sippuff")
        if not os.path.exists(config_dir):
            os.makedirs(config_dir)
        self.config_file = os.path.join(config_dir, "sippuff_config.json")
        self.default_config_file = os.path.join(config_dir, "sippuff_defaults.json")
        
        # Standard-Werte (werden aus JSON geladen)
        self.default_values = self.load_defaults()
        
        # Aktuelle Werte
        self.current_values = self.default_values.copy()
        
        # Unicode-Symbole
        self.icons = {
            'sync': '⟲',         # Sync-Pfeil
            'save': '⬇',         # Download/Save
            'undo': '↶',         # Zurück-Pfeil
            'refresh': '↻',      # Refresh-Pfeil
        }
        
        # Drucktest-Fenster
        self.pressure_test_window = None
        self.pressure_test_active = False
        self.pressure_update_pending = False  # Verhindere Update-Stau
        
        # Erweiterte Einstellungen ausklappbar
        self.advanced_expanded = False
        
        # Arduino Settings empfangen
        self.receiving_settings = False
        self.arduino_settings = {}
        
        self.create_widgets()
        self.load_config()
        
    def load_defaults(self):
        """Lädt Standard-Werte aus JSON oder erstellt die Datei"""
        default_values = {
            'click_left': 10,      
            'click_double': 15,    
            'click_right': -10,    
            'scroll_up': -5,       
            'scroll_down': 5,      
            'scroll_speed': 1,     
            'scroll_enabled': True,
            'wavelength': 15,
            'period': 35,
            'deadzone': 25,
            'debounce': 500,
            'joystick_enabled': True
        }
        
        # Prüfe ob Defaults-Datei existiert
        if os.path.exists(self.default_config_file):
            try:
                with open(self.default_config_file, 'r') as f:
                    loaded = json.load(f)
                    default_values.update(loaded)
                    print(f"✓ Standard-Werte aus {self.default_config_file} geladen")
            except Exception as e:
                print(f"⚠ Fehler beim Laden der Defaults: {e}")
        else:
            # Erstelle Defaults-Datei beim ersten Start
            try:
                with open(self.default_config_file, 'w') as f:
                    json.dump(default_values, f, indent=2)
                print(f"✓ Standard-Werte in {self.default_config_file} gespeichert")
            except Exception as e:
                print(f"⚠ Fehler beim Erstellen der Defaults-Datei: {e}")
        
        return default_values
        
    def create_widgets(self):
        # Header mit Titel 
        header = ctk.CTkFrame(self.root, corner_radius=0, fg_color="transparent")
        header.pack(fill="x", padx=20, pady=(20, 10))
        
        # Titel
        left_header = ctk.CTkFrame(header, fg_color="transparent")
        left_header.pack(side="left", fill="both", expand=True)
        
        title = ctk.CTkLabel(left_header, text="Sip & Puff Controller", font=ctk.CTkFont(size=24, weight="bold"))
        title.pack(anchor="w")  
        
        subtitle = ctk.CTkLabel(left_header, text="Echtzeit-Konfiguration", font=ctk.CTkFont(size=12), text_color="gray")
        subtitle.pack(anchor="w")  
        
        # Drucktest-Button
        self.pressure_test_btn = ctk.CTkButton(header, text="Drucktest", 
                                              command=self.open_pressure_test,
                                              width=140,
                                              font=ctk.CTkFont(size=13, weight="bold"),
                                              state="disabled")  # Deaktiviert bis verbunden
        self.pressure_test_btn.pack(side="right", padx=5)
        
        # Scrollbarer Container für die einzelnen Blöcke
        scrollable_container = ctk.CTkScrollableFrame(self.root, corner_radius=10, fg_color="transparent")
        scrollable_container.pack(fill="both", expand=True, padx=20, pady=(0, 10))
        
        # scrollbarer Container
        main_frame = scrollable_container
        
        # Verbindungsbereich 
        conn_frame = ctk.CTkFrame(main_frame, corner_radius=10)
        conn_frame.pack(fill="x", pady=(0, 10))
        
        conn_title = ctk.CTkLabel(conn_frame, text="Verbindung", font=ctk.CTkFont(size=16, weight="bold"))
        conn_title.grid(row=0, column=0, columnspan=4, sticky="w", padx=15, pady=(15, 10))
        
        ctk.CTkLabel(conn_frame, text="Port:").grid(row=1, column=0, sticky="w", padx=15, pady=10)
        
        self.port_combo = ctk.CTkComboBox(conn_frame, width=200, state="readonly")
        self.port_combo.grid(row=1, column=1, padx=10, pady=10)
        self.refresh_ports()
        
        self.refresh_btn = ctk.CTkButton(conn_frame, text=self.icons['refresh'], command=self.refresh_ports, width=40)
        self.refresh_btn.grid(row=1, column=2, padx=5, pady=10)
        
        self.connect_btn = ctk.CTkButton(conn_frame, text="Verbinden", command=self.toggle_connection, width=120)
        self.connect_btn.grid(row=1, column=3, padx=15, pady=10)
        
        self.status_label = ctk.CTkLabel(conn_frame, text="● Nicht verbunden", text_color="red", font=ctk.CTkFont(size=12, weight="bold"))
        self.status_label.grid(row=2, column=0, columnspan=4, padx=15, pady=(0, 15))
        
        # Klick-Schwellwerte
        click_frame = ctk.CTkFrame(main_frame, corner_radius=10)
        click_frame.pack(fill="x", pady=(0, 10))
        
        click_title = ctk.CTkLabel(click_frame, text="Klick-Schwellwerte", 
                                   font=ctk.CTkFont(size=16, weight="bold"))
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

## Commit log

2025-12-14 Revise README with updated images and project info
    Updated images and project details in README.md, including new prototype images and links. Removed outdated sections and added hardware component links.
2025-12-14 Added Arduino Code
2025-12-17 Refactor click and scroll settings in configuration files and update GUI to support the added Pressure Test
2026-01-04 Create Stl Folder
2026-01-04 Added 3mf Files
    [Backcover.3mf, BallJointAdapter.3mf, Frontcover.3mf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]
2026-01-04 Added Stl Files
    [Backcover.stl, Frontcover.stl, Mainframe.stl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]
2026-01-04 Added Step Files
    [Backcover.step, Frontcover.step, Mainframe.step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]
